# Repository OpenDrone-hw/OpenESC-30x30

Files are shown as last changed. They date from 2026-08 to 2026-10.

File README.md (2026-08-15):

# OpenESC-30x30

Open source 4-in-1 BLDC ESC with a 30.5 x 30.5 mm mounting pattern, part of the
incutec OpenDrone line. Four independent motor controllers, each with its own
MCU, gate driver and six MOSFETs, running AM32 and taking DShot over the
standard 8-pin connector.

<p>
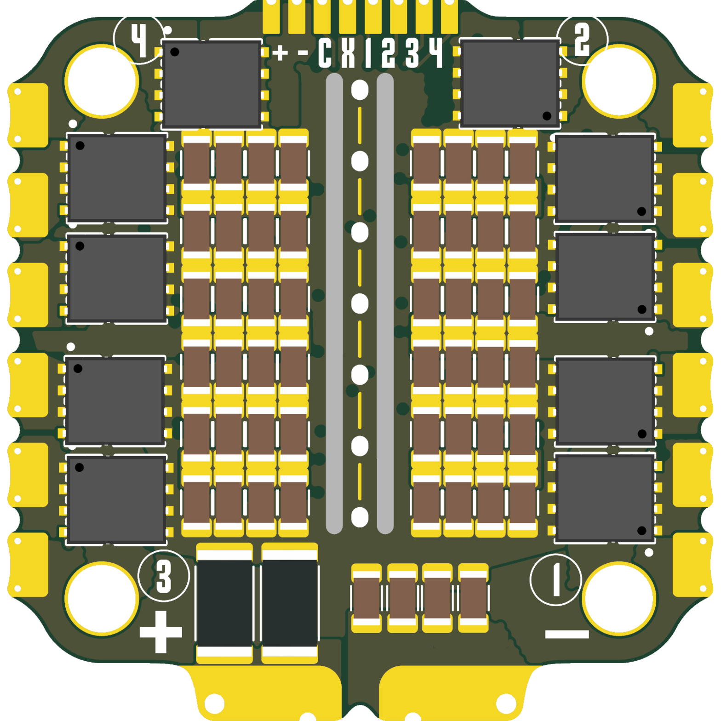
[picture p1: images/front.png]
OpenESC-30x30 top

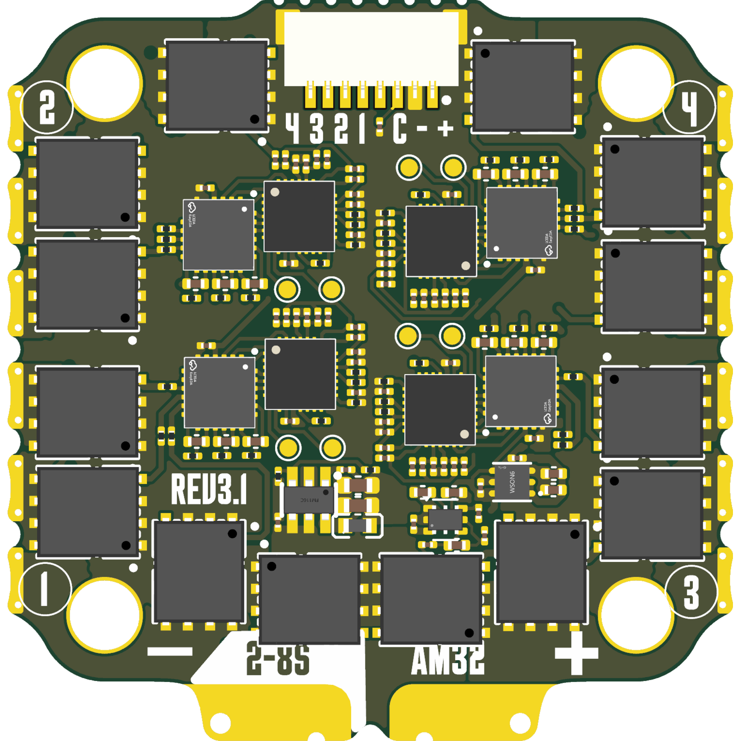
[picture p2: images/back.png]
OpenESC-30x30 bottom

</p>







Maintained by [@Just4Stan](https://github.com/Just4Stan).

## Specifications

| | |
|---|---|
| Continuous | 60 A / channel |
| Firmware | AM32 |
| ESC protocol | DShot, bidirectional |
| Telemetry | Extended DShot |
| Input | 2-8S LiPo (6.0-33.6 V) |
| BEC | None |
| MCU | One per motor |
| MOSFETs | 6 per motor |
| Current sense | On-board, 330 A |
| FC connector | JST-SH 8-pin |
| Mounting | 30.5 x 30.5 mm, 4.0 mm holes |
| Dimensions | 41.6 x 42.5 mm |
| PCB | 6-layer, 1.6 mm, 2 oz copper |

Technical write-up, part list and layout constraints: [AGENTS.md](AGENTS.md).

## In the line

What pairs with what, and what is available:
[opendrone.be](https://opendrone.be).

## Contributing

See [CONTRIBUTING.md](CONTRIBUTING.md).

## License

Hardware licensed under [CERN-OHL-S-2.0](https://ohwr.org/cern_ohl_s_v2.txt),
see [LICENSE](LICENSE).

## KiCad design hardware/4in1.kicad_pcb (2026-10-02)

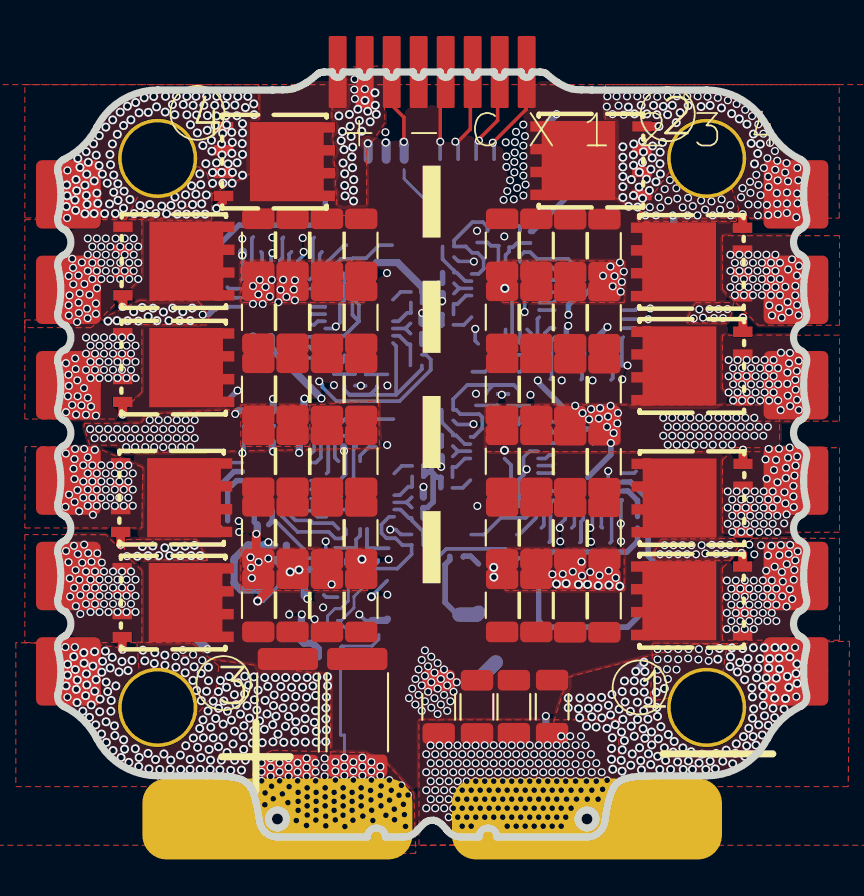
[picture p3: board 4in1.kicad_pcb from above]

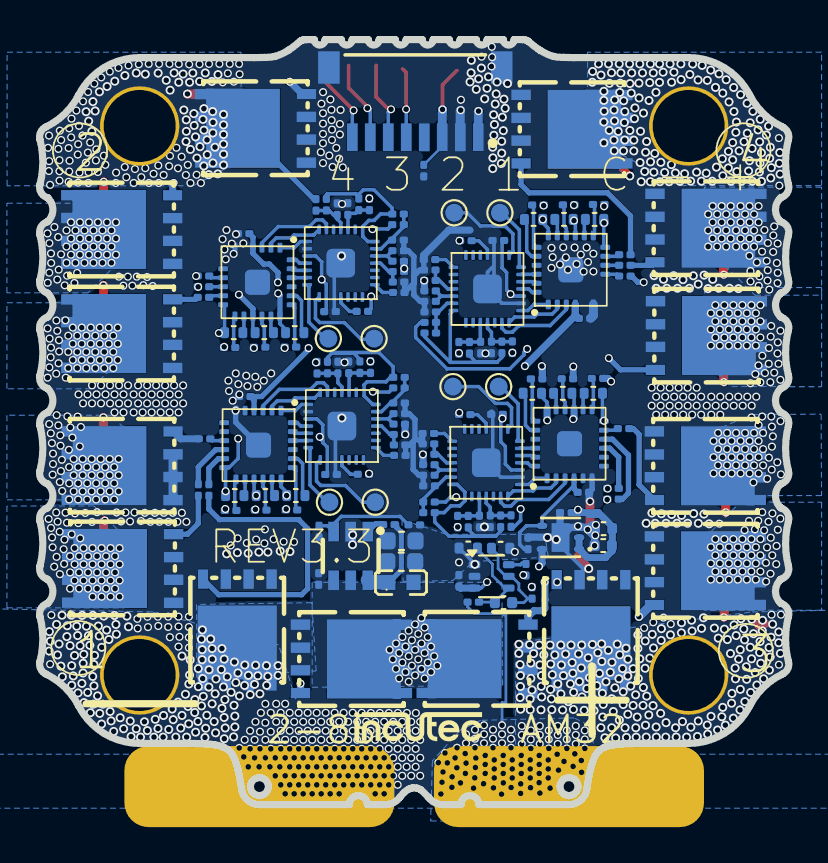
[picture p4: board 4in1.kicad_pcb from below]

Board: 6 copper layers, 41.6 x 42.5 mm, 222 parts (157 on the bottom side), 152 nets.

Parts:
C2, C2#2, C3, C3#2, C6, C8, C9, C13, C13#2, C13#3, C14, C14#2, C14#3, C17, C18, C26, C26#2, C26#3, C27, C27#2, C27#3, C30, C43, C43#2, C43#3, C44, C44#2, C44#3, C69, C70, C82, C82#2, C82#3, C83, C83#2, C83#3, C84, C84#2, C84#3, C85, C85#2, C85#3, C96, C97, C98, C99, C107, C107#2, C107#3, C108, C108#2, C108#3: 4.7uF; C_1206_3216Metric
C4, C51: 22uF; C_0402_1005Metric
C32, C33, C34, C35, C36, C37, C38, C39, C40, C41, C53, C56, C62, C67: 100nF; C_0402_WIDE
C42: 1uF; C_0402_1005Metric
C47, C86: 22uF; C_0603_1608Metric
C48, C49, C50, C52, C54, C55, C57, C58, C59, C60, C61, C63, C64, C65, C66, C68, C74, C75, C76, C81, C93, C94: 100nF; C_0201_0603Metric
J1: SM08B-SRSS-TB; JST_SM08B-SRSS-TB
Q1, Q2, Q3, Q4, Q5, Q6, Q7, Q8, Q9, Q10, Q11, Q12, Q13, Q14, Q15, Q16, Q17, Q18, Q19, Q20, Q21, Q22, Q23, Q24: SP40N01GHNK; PDFN-8L_L6.0-W5.0-P1.27
R10, R12, R13, R15, R25, R27, R28, R30, R31, R33, R34, R36, R46, R48, R49, R51, R52, R54, R64, R66, R67, R69, R70, R72: 10k; C_0201_0603Metric
R11, R14, R26, R29, R32, R35, R47, R50, R53, R65, R68, R71, R73, R89, R90: 1k; C_0201_0603Metric
R18, R19, R21, R22, R40, R41, R58, R59, R121: 10k; R_0201_0603Metric
R20, R39, R57, R87: 220R; R_0201_0603Metric
R23, R24, R37, R38, R42, R43, R44, R45, R55, R56, R60, R61, R62, R63, R74, R75, R76, R77, R78, R79, R80, R81, R82, R83: 15R; R_0201_0603Metric
R84, R85, R86, R88: 10R; R_0201_0603Metric
R120: 115k; R_0201_0603Metric
Rsense1, Rsense2: 0.2mR; R_2512_6332Metric
TP1, TP2, TP3, TP4, TP5, TP6, TP7, TP8: TestPoint; TestPoint_Pad_D1.0mm
U2, U5, U7, U9: AT32F421G8U7; QFN-28_L4.0-W4.0-P0.40-TL-EP2.4
U3: 4in1ESC30x30
U4, U6, U8, U10: NSG2065Q; QFN-24_L4.0-W4.0-P0.50-TL-EP2.8
U12: INA186A3IDCKR; SOT-363_SC-70-6
U13: LMR54406DBVR; SOT-23-6_L2.9-W1.6-P0.95-LS2.8-BR
U14: FTC160808S4R7MBCA; IND-SMD_L1.6-W0.8_FTC160865SR47MBCA
U15: TLV76733DRVR; WSON-6_L2.0-W2.0-P0.65-TL-EP

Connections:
+3V3: C4.2, C49.1, C51.2, C55.1, C61.1, C66.1, C81.1, C93.1, R18.2, R21.2, R40.2, R58.2, R84.2, R85.2, R86.2, R88.2, U2.17 (VDD), U5.17 (VDD), U7.17 (VDD), U9.17 (VDD), U12.3 (VS), U15.1 (OUT), U15.2 (FB/SNS)
+10V: C47.1, C57.1, C58.1, C63.1, C68.1, C76.1, C86.1, R120.1, U4.4 (VCC), U6.4 (VCC), U8.4 (VCC), U10.4 (VCC), U14.2, U15.4 (EN), U15.6 (IN)
+BATT: C2.1, C2#2.1, C3.1, C3#2.1, C6.1, C8.1, C9.1, C13.1, C13#2.1, C13#3.1, C14.1, C14#2.1, C14#3.1, C17.1, C18.1, C26.1, C26#2.1, C26#3.1, C27.1, C27#2.1, C27#3.1, C30.1, C43.1, C43#2.1, C43#3.1, C44.1, C44#2.1, C44#3.1, C69.1, C70.1, C74.1, C82.1, C82#2.1, C82#3.1, C83.1, C83#2.1, C83#3.1, C84.1, C84#2.1, C84#3.1, C85.1, C85#2.1, C85#3.1, C96.1, C97.1, C98.1, C99.1, C107.1, C107#2.1, C107#3.1, C108.1, C108#2.1, C108#3.1, J1.1, Q1.3 (D), Q6.3 (D), Q7.3 (D), Q8.3 (D), Q9.3 (D), Q10.3 (D), Q13.3 (D), Q16.3 (D), Q17.3 (D), Q18.3 (D), Q19.3 (D), Q20.3 (D), R89.2, Rsense1.2, Rsense2.2, U3.3 (VBAT+), U13.4 (EN), U13.5 (VIN)
/CSA+: R90.2, Rsense1.1, Rsense2.1, U3.1 (VBAT)
/CURR: C94.1, J1.3, R73.1, U3.5 (CUR)
/ESC1/AH: U2.20 (PA10), U4.22 (HIN1)
/ESC1/AL: U2.15 (PB1), U4.1 (LIN1)
/ESC1/BH: U2.19 (PA9), U4.23 (HIN2)
/ESC1/BL: U2.14 (PB0), U4.2 (LIN2)
/ESC1/CH: U2.18 (PA8), U4.24 (HIN3)
/ESC1/CL: U2.13 (PA7), U4.3 (LIN3)
/ESC1/FBA: R25.1, R26.2, R27.2, U2.6 (PA0)
/ESC1/FBB: R28.2, R29.2, R30.2, U2.10 (PA4)
/ESC1/FBC: R31.2, R32.2, R33.2, U2.11 (PA5)
/ESC1/FBCOMMON: R25.2, R28.1, R31.1, U2.7 (PA1)
/ESC1/GHA: R76.1, U4.19 (HO1)
/ESC1/GHB: R55.1, U4.16 (HO2)
/ESC1/GHC: R23.1, U4.13 (HO3)
/ESC1/GLA: R80.1, U4.11 (LO1)
/ESC1/GLB: R62.1, U4.10 (LO2)
/ESC1/GLC: R42.1, U4.9 (LO3)
/ESC1/MotorA: C53.1, Q1.1 (S), Q2.3 (D), R27.1, U3.23 (1A), U4.18 (VS1)
/ESC1/MotorB: C32.1, Q6.1 (S), Q11.3 (D), R30.1, U3.22 (1B), U4.15 (VS2)
/ESC1/MotorC: C36.1, Q16.1 (S), Q21.3 (D), R33.1, U3.21 (1C), U4.12 (VS3)
/ESC1/vdda: C48.1, R84.1, U2.5 (VDDA)
/ESC2/AH: U5.20 (PA10), U6.22 (HIN1)
/ESC2/AL: U5.15 (PB1), U6.1 (LIN1)
/ESC2/BH: U5.19 (PA9), U6.23 (HIN2)
/ESC2/BL: U5.14 (PB0), U6.2 (LIN2)
/ESC2/CH: U5.18 (PA8), U6.24 (HIN3)
/ESC2/CL: U5.13 (PA7), U6.3 (LIN3)
/ESC2/FBA: R10.1, R11.2, R12.2, U5.6 (PA0)
/ESC2/FBB: R13.2, R14.2, R15.2, U5.10 (PA4)
/ESC2/FBC: R34.2, R35.2, R36.2, U5.11 (PA5)
/ESC2/FBCOMMON: R10.2, R13.1, R34.1, U5.7 (PA1)
/ESC2/GHA: R77.1, U6.19 (HO1)
/ESC2/GHB: R56.1, U6.16 (HO2)
/ESC2/GHC: R24.1, U6.13 (HO3)
/ESC2/GLA: R81.1, U6.11 (LO1)
/ESC2/GLB: R63.1, U6.10 (LO2)
/ESC2/GLC: R43.1, U6.9 (LO3)
/ESC2/MotorA: C56.1, Q3.3 (D), Q7.1 (S), R12.1, U3.20 (2B), U6.18 (VS1)
/ESC2/MotorB: C33.1, Q8.1 (S), Q12.3 (D), R15.1, U3.19 (2C), U6.15 (VS2)
/ESC2/MotorC: C37.1, Q17.1 (S), Q22.3 (D), R36.1, U3.18 (2A), U6.12 (VS3)
/ESC2/vdda: C54.1, R85.1, U5.5 (VDDA)
/ESC3/AH: U7.20 (PA10), U8.22 (HIN1)
/ESC3/AL: U7.15 (PB1), U8.1 (LIN1)
/ESC3/BH: U7.19 (PA9), U8.23 (HIN2)
/ESC3/BL: U7.14 (PB0), U8.2 (LIN2)
/ESC3/CH: U7.18 (PA8), U8.24 (HIN3)
/ESC3/CL: U7.13 (PA7), U8.3 (LIN3)
/ESC3/FBA: R46.1, R47.2, R48.2, U7.6 (PA0)
/ESC3/FBB: R49.2, R50.2, R51.2, U7.10 (PA4)
/ESC3/FBC: R52.2, R53.2, R54.2, U7.11 (PA5)
/ESC3/FBCOMMON: R46.2, R49.1, R52.1, U7.7 (PA1)
/ESC3/GHA: R78.1, U8.19 (HO1)
/ESC3/GHB: R60.1, U8.16 (HO2)
/ESC3/GHC: R37.1, U8.13 (HO3)
/ESC3/GLA: R82.1, U8.11 (LO1)
/ESC3/GLB: R74.1, U8.10 (LO2)
/ESC3/GLC: R44.1, U8.9 (LO3)
/ESC3/MotorA: C62.1, Q4.3 (D), Q13.1 (S), R48.1, U3.15 (3B), U8.18 (VS1)
/ESC3/MotorB: C34.1, Q9.1 (S), Q14.3 (D), R51.1, U3.16 (3C), U8.15 (VS2)
/ESC3/MotorC: C38.1, Q18.1 (S), Q23.3 (D), R54.1, U3.17 (3A), U8.12 (VS3)
/ESC3/vdda: C60.1, R86.1, U7.5 (VDDA)
/ESC4/AH: U9.20 (PA10), U10.22 (HIN1)
/ESC4/AL: U9.15 (PB1), U10.1 (LIN1)
/ESC4/BH: U9.19 (PA9), U10.23 (HIN2)
/ESC4/BL: U9.14 (PB0), U10.2 (LIN2)
/ESC4/CH: U9.18 (PA8), U10.24 (HIN3)
/ESC4/CL: U9.13 (PA7), U10.3 (LIN3)
/ESC4/FBA: R64.1, R65.2, R66.2, U9.6 (PA0)
/ESC4/FBB: R67.2, R68.2, R69.2, U9.10 (PA4)
/ESC4/FBC: R70.2, R71.2, R72.2, U9.11 (PA5)
/ESC4/FBCOMMON: R64.2, R67.1, R70.1, U9.7 (PA1)
/ESC4/GHA: R79.1, U10.19 (HO1)
/ESC4/GHB: R61.1, U10.16 (HO2)
/ESC4/GHC: R38.1, U10.13 (HO3)
/ESC4/GLA: R83.1, U10.11 (LO1)
/ESC4/GLB: R75.1, U10.10 (LO2)
/ESC4/GLC: R45.1, U10.9 (LO3)
/ESC4/MotorA: C67.1, Q5.3 (D), Q19.1 (S), R66.1, U3.12 (4A), U10.18 (VS1)
/ESC4/MotorB: C35.1, Q10.1 (S), Q15.3 (D), R69.1, U3.13 (4B), U10.15 (VS2)
/ESC4/MotorC: C39.1, Q20.1 (S), Q24.3 (D), R72.1, U3.14 (4C), U10.12 (VS3)
/ESC4/vdda: C65.1, R88.1, U9.5 (VDDA)
/M1: J1.5, R20.1, U3.7 (M1)
/M2: J1.6, R39.1, U3.8 (M2)
/M3: J1.7, R57.1, U3.9 (M3)
/M4: J1.8, R87.1, U3.10 (M4)
GND: C2.2, C2#2.2, C3.2, C3#2.2, C4.1, C6.2, C8.2, C9.2, C13.2, C13#2.2, C13#3.2, C14.2, C14#2.2, C14#3.2, C17.2, C18.2, C26.2, C26#2.2, C26#3.2, C27.2, C27#2.2, C27#3.2, C30.2, C40.2, C41.2, C43.2, C43#2.2, C43#3.2, C44.2, C44#2.2, C44#3.2, C47.2, C48.2, C49.2, C50.2, C51.1, C52.2, C54.2, C55.2, C57.2, C58.2, C59.2, C60.2, C61.2, C63.2, C64.2, C65.2, C66.2, C68.2, C69.2, C70.2, C74.2, C76.2, C81.2, C82.2, C82#2.2, C82#3.2, C83.2, C83#2.2, C83#3.2, C84.2, C84#2.2, C84#3.2, C85.2, C85#2.2, C85#3.2, C86.2, C93.2, C94.2, C96.2, C97.2, C98.2, C99.2, C107.2, C107#2.2, C107#3.2, C108.2, C108#2.2, C108#3.2, J1.2, J1.P1 (MP1), J1.P2 (MP2), Q2.1 (S), Q3.1 (S), Q4.1 (S), Q5.1 (S), Q11.1 (S), Q12.1 (S), Q14.1 (S), Q15.1 (S), Q21.1 (S), Q22.1 (S), Q23.1 (S), Q24.1 (S), R11.1, R14.1, R19.2, R22.2, R26.1, R29.1, R32.1, R35.1, R41.2, R47.1, R50.1, R53.1, R59.2, R65.1, R68.1, R71.1, R121.2, U2.16 (VSS), U2.29 (VSS), U3.2 (BATGND), U3.4 (GND), U3.11 (Hole), U4.6 (COM), U4.25 (COM), U5.16 (VSS), U5.29 (VSS), U6.6 (COM), U6.25 (COM), U7.16 (VSS), U7.29 (VSS), U8.6 (COM), U8.25 (COM), U9.16 (VSS), U9.29 (VSS), U10.6 (COM), U10.25 (COM), U12.1 (REF), U12.2 (GND), U13.2 (GND), U15.3 (GND), U15.5 (GND), U15.7 (EP)
unnamed: Q1.2 (G), R76.2
unnamed: Q2.2 (G), R80.2
unnamed: Q3.2 (G), R81.2
unnamed: Q4.2 (G), R82.2
unnamed: Q5.2 (G), R83.2
unnamed: Q6.2 (G), R55.2
unnamed: Q7.2 (G), R77.2
unnamed: Q8.2 (G), R56.2
unnamed: Q9.2 (G), R60.2
unnamed: Q10.2 (G), R61.2
unnamed: Q11.2 (G), R62.2
unnamed: Q12.2 (G), R63.2
unnamed: Q13.2 (G), R78.2
unnamed: Q14.2 (G), R74.2
unnamed: Q15.2 (G), R75.2
unnamed: Q16.2 (G), R23.2
unnamed: Q17.2 (G), R24.2
unnamed: Q18.2 (G), R37.2
unnamed: Q19.2 (G), R79.2
unnamed: Q20.2 (G), R38.2
unnamed: Q21.2 (G), R42.2
unnamed: Q22.2 (G), R43.2
unnamed: Q23.2 (G), R44.2
unnamed: Q24.2 (G), R45.2
unnamed: R19.1, U2.1 (BOOT0)
unnamed: C50.1, R18.1, U2.4 (NRST)
unnamed: TP1.1 (1_1), U2.21 (PA13)
unnamed: TP4.1 (1_1), U2.22 (PA14)
unnamed: R20.2, U2.25 (PB4)
unnamed: C53.2, U4.20 (VB1)
unnamed: C32.2, U4.17 (VB2)
unnamed: C36.2, U4.14 (VB3)
unnamed: R22.1, U5.1 (BOOT0)
unnamed: C52.1, R21.1, U5.4 (NRST)
unnamed: TP2.1 (1_1), U5.21 (PA13)
unnamed: TP5.1 (1_1), U5.22 (PA14)
unnamed: R39.2, U5.25 (PB4)
unnamed: C56.2, U6.20 (VB1)
unnamed: C33.2, U6.17 (VB2)
unnamed: C37.2, U6.14 (VB3)
unnamed: R41.1, U7.1 (BOOT0)
unnamed: C59.1, R40.1, U7.4 (NRST)
unnamed: TP3.1 (1_1), U7.21 (PA13)
unnamed: TP6.1 (1_1), U7.22 (PA14)
unnamed: R57.2, U7.25 (PB4)
unnamed: C62.2, U8.20 (VB1)
unnamed: C34.2, U8.17 (VB2)
unnamed: C38.2, U8.14 (VB3)
unnamed: R59.1, U9.1 (BOOT0)
unnamed: C64.1, R58.1, U9.4 (NRST)
unnamed: TP7.1 (1_1), U9.21 (PA13)
unnamed: TP8.1 (1_1), U9.22 (PA14)
unnamed: R87.2, U9.25 (PB4)
unnamed: C67.2, U10.20 (VB1)
unnamed: C35.2, U10.17 (VB2)
unnamed: C39.2, U10.14 (VB3)
unnamed: C41.1, C42.2, R90.1, U12.4 (+IN)
unnamed: C40.1, C42.1, R89.1, U12.5 (-IN)
unnamed: R73.2, U12.6 (OUT)
unnamed: C75.2, U13.1 (CB)
unnamed: R120.2, R121.1, U13.3 (FB)
unnamed: C75.1, U13.6 (SW), U14.1

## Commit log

2026-08-04 chore: wire shared Incutec KiCad library
    Adds incutec-hw/KiCad-Library as submodule at libs/KiCad-Library, pinned
    to the feat/complete-library build. Project lib tables gain the Incutec
    sym+fp entries via ${KIPRJMOD} relative paths. Existing local libraries
    untouched (frozen, see the library repo MANIFEST).
2026-08-04 chore: bump KiCad-Library submodule pin
2026-08-05 docs: apply repo-standard review findings
    - Remove internal working notes from the tree: hardware/database/
    (cap_analysis.md, project.db), now gitignored as internal documents
    - CONTRIBUTING.md: drop aspirational contribution-terms sentence
    - DESIGN.md: cite only the tracked KiCad design files, drop the
    gitignored production BOM path, point revision detail at CHANGELOG.md
    - DESIGN.md: link the canonical AM32 repo (am32-firmware/AM32)
    - THIRD_PARTY.md: drop forward-looking closing line
    - .gitignore: stop ignoring authored *.kicad_dru, fix broken **/.step
    pattern to hardware/*.step, untrack generated hardware/4in1.step
    - Track hardware/fabrication-toolkit-options.json so exports are
    re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
2026-08-05 hardware: track panel design rules (surfaced by gitignore fix)
2026-08-05 Fix old OpenESC_20X20 slug in CHANGELOG and DESIGN docs
    Renamed repo slug OpenESC_20X20 to OpenESC-20x20 in prose and links.
    The .kicad_pro dash findings are handled in a separate pass.
2026-08-06 Rewrite CONTRIBUTING for humans: file locking, render proof, sign-off
    KiCad files cannot be merged, so the doc now leads with claiming files via
    git lfs lock and issue-first discussion, the convention used by LumenPnP and
    Ultimate Hacking Keyboard. Adds .gitattributes marking design files lockable.
    Drops the internal documentation-style rule that meant nothing to contributors.
2026-08-06 docs: fix contradictions and deduplicate docs
    - README: `Rev1-30x30` comes from 4in1.kicad_pcb; the tracked
    fabrication-toolkit-options.json (ARCHIVE_NAME Rev1-30x30+20x20) belongs to
    the combined panel export, written out as Rev1-30x3020x20.
    - DESIGN.md: 4in1-panel.kicad_pcb is the combined 30x30 + 20x20 production
    panel (both outlines, 8 MCUs, SP40N01GHNK plus the 20x20 DOY180N03T), not a
    panel of this board alone.
    - THIRD_PARTY.md: add the missing `hardware/` prefix to the two 3D model paths.
    - licensing/README.md: GitHub does not auto-detect CERN-OHL-S-2.0, it reports
    NOASSERTION; root LICENSE is the authoritative text.
    - Deduplicate: drop the README spec table (kept in DESIGN.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
2026-08-06 Local libraries are the working default again
    New parts go into this repo's local libraries. KiCad-Library becomes a mirror
    of parts we already use or stock, worth checking first because a hit means we
    have sourced it before. Promotion into it is a separate step.
2026-08-08 Fix JST 3D model in lib, add wrl, re-render board images
    The JST SM08B footprint used a STEP model whose housing renders on
    stilts past the board edge. Replaced with the proven VRML model from
    OpenFC-Lite (same physical part) at the geometrically derived offset
    (-3.5, 2.17, 0), which seats the housing at the edge with the leads on
    their pads, identical to the FC boards. Board-instance fixes for J1 and
    U12 (SOT-363 moved from the global KiCad model to the project-local
    SC-70-6) are in the working tree mixed with uncommitted layout work and
    will be committed with it; renders reflect that current state, verified
    IC by IC on both sides.
2026-08-08 chore: point every GitHub link at OpenDrone-hw (#18)
    * Fix JST 3D model in lib, add wrl, re-render board images
    Co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
2026-08-11 docs: ask contributors to raise proposals in Discord first
    CONTRIBUTING.md now points at the Discord server and asks contributors to tag
    the developers before opening an issue or starting work, so proposals get
    checked against work in progress, board locks and committed production runs.
2026-08-11 Rev 3: 8S rating, input TVS removed
    The 3x SMBJ24A are removed. Their 24 V standoff sits below the 33.6 V a full 8S
    pack reaches, so they conducted rather than protected. There is no input clamp
    now; the 3S-8S rating rests on bench and flight testing on 8S.
    README and DESIGN.md updated: 3S-8S, no TVS, and the envelope stated in terms
    of the SP40N01GHNK MOSFET (40 V VDSS), the LMR54406DBVR buck (36 V rated, 45 V
    absolute maximum, 50 V short transient) and the ~330 A current-sense
    full-scale.
    ERC and DRC reviewed by the maintainer.
    [4in1.kicad_sch, ESC.kicad_sch]
2026-08-13 Standardise: merge DESIGN.md and CLAUDE.md into AGENTS.md, trim README
    Adopts the org-wide shape. Four root files, CONTRIBUTING is a stub pointing at
    OpenDrone-hw/.github, .gitignore and .gitattributes are the canonical copies.
    AGENTS.md replaces hardware/docs/DESIGN.md and the gitignored CLAUDE.md, which
    duplicated each other and disagreed. Written from the design files rather than
    from either document, which caught two stale claims CLAUDE.md was carrying:
    it described 2S-6S input and "input clamp: 3x SMBJ24A TVS", but no TVS exists
    in the schematic or on the board, and the project is KiCad 10, not 9.
    Adds hardware/4in1.kicad_dru, which this repo did not have at all despite
    CONVENTIONS na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
2026-08-13 Drop licensing/, keep only the notice that is real (#21)
    Three files, of which one was load-bearing:
    - README.md was commentary about the other two. Gone.
    - TRADEMARKS.md claimed protection over OpenDrone names, logos and branding.
    OpenDrone is not trademarked; incutec is. The accurate version is now stated
    once in the org document instead of overclaimed in each repo.
    - THIRD_PARTY.md recorded that two bundled STEP files embed CC-BY-SA and GPL
    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
2026-08-13 README: standardised link row, specs from the shop, status badge (#22)
    Same shape in every board repo.
    Outbound links move out of prose into one badge row: status, shop, the product's
    Discord channel, its build video, and OSHWA where the board is certified. The
    status badge links to the stage ladder in the org CONTRIBUTING rather than
    describing the stage here.
    The specification table is synced from the product page on opendrone.be, which
    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
2026-08-14 chore: bump KiCad-Library submodule pin to 8f8093b
2026-08-14 Normalise board setup to the line standard
    The canonical dru's copper-to-copper rule demanded 0.1 mm outer
    clearance against the 0.09 line standard stated in the same file,
    flooding DRC with false errors on standard-routed boards. Removed;
    the project-file floors gate this already. Rule floors set to the
    line standard where the routed board complies, verified by DRC:
    zero new violations.
2026-08-14 Drop the KiCad-Library submodule: nothing references it
    No symbol, footprint or 3D model in the design resolves through
    libs/KiCad-Library; every part is in the repo's local libraries. The
    submodule only cost --recursive clones and pin maintenance. Lib-table
    rows for the dead Incutec nickname removed so KiCad stops warning.
2026-08-14 Rev 3.1 working state: flashing and QC fixtures, board work
    New 30x30-ESC-Flashing and 30x30-ESC-QC fixture projects, main board
    PCB updates (PCB-only bulk cap bank per the container LOG), shop badge
    gold. Internal documents and regenerable fixture STEPs stay local via
    the repo-specific .gitignore tail.
    [30x30-ESC-Flashing.kicad_pcb, 30x30-ESC-Flashing.kicad_sch, 30x30-ESC-QC.kicad_pcb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]
2026-08-14 Rev 3.1 release prep: export session state, renders, revisions
    The committed board now matches the verified fab export exactly
    (check_export.py C1-C3 clean). Renders regenerated from it.
2026-08-14 Correct the bulk cap numbers, measured from the board and BOM
2026-08-15 docs: standardise AGENTS.md and complete spec table
    AGENTS.md rebuilt on the org template, every claim netlist-verified. README spec table completed: 60 A per channel, 2-8S input, dimensions 41.6 x 42.5 mm, 1.6 mm PCB, maintainer added. DOC text varia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
2026-08-15 docs: add voltage range to input spec
    Input row now reads 2-8S LiPo (6.0-33.6 V).
2026-08-15 Move the QC fixture and flashing jig to OpenDrone-Fixtures
    30x30-ESC-QC and 30x30-ESC-Flashing now live in
    OpenDrone-hw/OpenDrone-Fixtures as OpenESC-30x30-QC and
    OpenESC-30x30-Flashing, history included. AGENTS links there.
    [30x30-ESC-Flashing.kicad_pcb, 30x30-ESC-Flashing.kicad_sch, 30x30-ESC-QC.kicad_pcb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]
2026-08-18 docs(agents): record the 470 uF supplied with every board
    The board ships with a 470 uF electrolytic for the user to solder across
    the battery terminals, the standard pairing of on-board ceramics with a
    pack-side elco. It was written down nowhere, while it dominates the bus
    capacitance once installed and therefore sets hot-plug and braking
    behaviour and the emission spectrum.
    Recorded as a supplied-not-fitted part so anything reading the parts table
    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
2026-08-22 CSA input filter: starve the high-side feedthrough before the amplifier
    /CURR was garbage below full throttle, measured 2026-08-21 on the 20x20
    sibling: bus common-mode at 24-54 kHz rectifies in the INA186 front end,
    whose CMRR is ~80 dB there against an 8 mV full-scale signal.
    R89/R90 1k (C270365) in each sense leg, C40/C41 100n 50V (C307331) to
    ground, C42 1u (C7500381) across the amplifier inputs. Worst-case SPICE
    (1% R, 10% C mismatch, 10 Vpp CM at 50 kHz): common-mode at the pins
    drops 300x, converted differential ripple 2.8 mVpp, DC gain error
    -0.08 percent. C42 does the load-bearing work: without it the C40/C41
    mismatch converts CM to 59 mVpp of differential, 7x full scale. Values
    ho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
    [4in1.kicad_pcb, 4in1.kicad_sch]
2026-08-22 rev3.2: release artifacts, renders, docs for the CSA input network
    Gates G1-G6 pass: baselines updated (recorded maintainer decision,
    'ship as is'), fab set OpenESC-30x30-rev3.2 checked consistent against
    board and schematic, STEP and schematic PDF exported, README renders
    regenerated, site art regenerated in OpenDrone-Web (uncommitted there).
    [4in1.kicad_pcb]
2026-08-22 3D models: retarget to KiCad stock, fix placement
    Replaces easyeda2kicad 3D models with KiCad's own where a dimension-matched
    equivalent exists. The easyeda models run 20-100x denser for the same package
    and most carry the LCEDA watermark modelled as raised geometry, which renders
    on every CAD picture of the board and is not on the real part.
    Only the (model ...) reference, offset and rotation are touched. No footprint,
    pad, land pattern, net, placement or value is modified. Applied to the footprint
    LIBRARY and the boards together: fixing only the .pretty is invisible because
    each board carries its own footprint copy, and fixing only the .kicad_pcb is
    surface level because the next placemen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
2026-09-18 Align AGENTS.md with template conventions (#40)
    * Align AGENTS.md with template conventions
    Claude-Session: https://claude.ai/code/session_01GiFxVPcfpNcHY5feGsgG83
    * Reorder AGENTS.md sections: design first, agent mechanics last
    New order: Architecture, (Voltage envelope,) Power, Key parts, Connectors
    and I/O, (GPIO map, Using it on a base,) Layout rules, Firmware, Repo,
    (Parts and datasheets,) Environment, Rules, Revisions.
    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
2026-10-02 Fix JLCPCB placement offsets in the toolkit config (#43)
    Mirror of OpenESC-20x20 #45. AUTO TRANSLATE applied the toolkit's
    generic QFN (+90) and SOT-23/SOT-363 (+180) rules to EasyEDA-derived
    footprints that already match the JLCPCB library. Disable it and set
    explicit offsets measured against the EasyEDA footprints:
    - U12 (C2058245): FT Rotation Offset 270
    - Q1-Q24 (C22385416): FT Position Offset 0,-1.06
    - J1 (C160407): FT Position Offset 0,2.835
    Metadata only: netlist differs by the new fields, ERC/DRC unchanged.
    [4in1.kicad_pcb, 4in1.kicad_sch, ESC.kicad_sch]
2026-11-11 chore: KiCad 10 project settings re-save (#50)
    KiCad 10 rewrites the project file on save: the zone defaults block is written out in full (KiCad defaults, min_clearance unchanged) and the text variables are sorted alphabetically. No design rule, 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
2026-11-11 docs(rules): kicad-skip cannot round-trip KiCad 10 schematics (#51)
    Syncs the shared Rules section from OpenDrone-hw/hardware-template (PR 16).
